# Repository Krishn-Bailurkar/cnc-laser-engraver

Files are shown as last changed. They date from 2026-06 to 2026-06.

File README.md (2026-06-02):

# 🛠️ CNC Laser Engraver Machine

Welcome to the official repository for the **CNC Laser Engraver Machine** project. This is a comprehensive Mechatronics Capstone Project designed to create an adaptable, high-precision, and cost-effective CNC laser engraving platform. 

This repository contains the complete **3D-printable STL model files** for all mechanical components, as well as the project documentation.

---

## 📋 Table of Contents
1. [Project Overview](#-project-overview)
2. [Technical Specifications](#%EF%B8%8F-technical-specifications)
3. [Repository Structure (3D Models)](#%EF%B8%8F-repository-structure-3d-models)
4. [Hardware & Bill of Materials (BOM)](#-hardware--bill-of-materials-bom)
5. [Assembly & Fabrication Guide](#-assembly--fabrication-guide)
6. [Software & Control Configuration](#-software--control-configuration)
7. [Testing & Validation](#-testing--validation)

---

## 🌟 Project Overview

Our goal was to design and develop a CNC (Computer Numerical Control) laser engraver machine capable of engraving various materials such as **wood, acrylic, leather, and metal**. 

The design is built on three core pillars:
*   **Accuracy:** Intricate and high-speed motion control.
*   **Repeatability:** Consistent engraving results across multiple production runs.
*   **Efficiency & Adaptability:** No proprietary hardware/software; customizable to any size or shape.

---

## ⚙️ Technical Specifications

### 📏 Workspace & Dimensions
*   **Engraving Area (Workspace):** $700\text{ mm} \times 700\text{ mm} \times 50\text{ mm}$ ($X, Y, Z$ axes)
*   **Table Size:** $970\text{ mm} \times 979\text{ mm}$ (Outer edges of feet)
*   **Total Machine Footprint:** $1072\text{ mm} \times 1081\text{ mm} \times 540\text{ mm}$ (Clearance of $680\text{ mm}$ to remove Z-axis)

### ⚡ Electrical & Control System
*   **Laser Module:** 5.5W Diode Laser (Wavelength: $450\text{ nm}$, Input Voltage: 12V DC/AC, Active cooling)
*   **Control Board:** Arduino UNO (ATmega328P microcontroller)
*   **Shield:** Arduino CNC Shield V3
*   **Motor Drivers:** A4988 Stepper Motor Drivers (supports full to $1/16$ microstepping, continuous $1\text{A}$ per phase)
*   **Stepper Motors:** NEMA 17 Stepper Motors (12V DC, $1.2\text{A}$ current, $1.8^\circ$ step angle, $22.2\text{ Oz-in}$ unipolar holding torque)
*   **Power Supply:** Switched-Mode Power Supply (SMPS) 12V $5\text{A}$ ($60\text{W}$ rated power)
*   **Motion Transfer:** GT2 Timing Belts (10mm width, 2mm pitch) driven by 20-tooth aluminum pulleys

---

## 🛠️ Repository Structure (3D Models)

All 3D-printable parts are located in the [`STL/`](file:///d:/Krishn's folder/GitHub/CNC laser engerver/STL) directory. They should be printed with at least **45%+ infill** for strength (Core should be printed at **70% infill**).

| Qty | Part Name | STL File Path | Infill | Key Function |
| :--- | :--- | :--- | :---: | :--- |
| 1 | **Core** | [`STL/Core F .STL`](file:///d:/Krishn's folder/GitHub/CNC laser engerver/STL/Core%20F%20.STL) | 70% | The central carriage holding the Z-axis and laser head assembly. |
| 2 | **Corner Bottom** | [`STL/Corner Bottom F 1.stl`](file:///d:/Krishn's folder/GitHub/CNC laser engerver/STL/Corner%20Bottom%20F%201.stl) / [`F 2.STL`](file:///d:/Krishn's folder/GitHub/CNC laser engerver/STL/Corner%20Bottom%20F%202.STL) | 45% | Main corner mounts anchored to the workbench table. |
| 2 | **Corner Top** | [`STL/Corner Top F1.stl`](file:///d:/Krishn's folder/GitHub/CNC/laser/engerver/STL/Corner%20Top%20F1.stl) / [`F 2.STL`](file:///d:/Krishn's folder/GitHub/CNC/laser/engerver/STL/Corner%20Top%20F%202.STL) | 45% | Secure top caps holding the outer axis rails together. |
| 4 | **Feet** | [`STL/Feet F.STL`](file:///d:/Krishn's folder/GitHub/CNC laser engerver/STL/Feet%20F.STL) | 45% | Bottom mounting brackets that secure legs to the table. |
| 4 | **Corner Leg Lock** | [`STL/Corner Leg Lock F.STL`](file:///d:/Krishn's folder/GitHub/CNC laser engerver/STL/Corner%20Leg%20Lock%20F.STL) | 45% | Clamps that secure the vertical legs into the corner bases. |
| 2 | **Truck** | [`STL/Truck F .STL`](file:///d:/Krishn's folder/GitHub/CNC laser engerver/STL/Truck%20F%20.STL) / [`Truck F.stl`](file:///d:/Krishn's folder/GitHub/CNC laser engerver/STL/Truck%20F.stl) | 45% | Carriage blocks moving along the X and Y axes. |
| 4 | **Truck Clamp** | [`STL/Truck Clamp F .STL`](file:///d:/Krishn's folder/GitHub/CNC laser engerver/STL/Truck%20Clamp%20F%20.STL) | 45% | Secure clamping locks for the rail-bearing trucks. |
| 2 | **Lower Belt Mount** | [`STL/Lower Belt F1.stl`](file:///d:/Krishn's folder/GitHub/CNC laser engerver/STL/Lower%20Belt%20F1.stl) / [`F 2.STL`](file:///d:/Krishn's folder/GitHub/CNC laser engerver/STL/Lower%20Belt%20F%202.STL) | 45% | Bottom belt retention and routing guides. |
| 2 | **Upper Belt Mount** | [`STL/Upper Belt F 1.stl`](file:///d:/Krishn's folder/GitHub/CNC laser engerver/STL/Upper%20Belt%20F%201.stl) / [`F 2.STL`](file:///d:/Krishn's folder/GitHub/CNC/laser/engerver/STL/Upper%20Belt%20F%202.STL) | 45% | Top belt retention and tensioners. |
| 2 | **Core Z Clamp** | [`STL/Core Z Clamp 1 F .STL`](file:///d:/Krishn's folder/GitHub/CNC laser engerver/STL/Core%20Z%20Clamp%201%20F%20.STL) / [`2 F .STL`](file:///d:/Krishn's folder/GitHub/CNC laser engerver/STL/Core%20Z%20Clamp%202%20F%20.STL) | 45% | Holds the vertical Z rails in place on the central core. |
| 3 | **Core Clamp** | [`STL/Core Clamp F .STL`](file:///d:/Krishn's folder/GitHub/CNC laser engerver/STL/Core%20Clamp%20F%20.STL) | 45% | Main clamping block surrounding the core gantry rails. |
| 1 | **Core Clamp Y** | [`STL/Core Clamp Y F .STL`](file:///d:/Krishn's folder/GitHub/CNC laser engerver/STL/Core%20Clamp%20Y%20F%20.STL) | 45% | Y-axis alignment clamp for the core carriage. |
| 1 | **Lower Tool Plate** | [`STL/Lower Tool Plate F.STL`](file:///d:/Krishn's folder/GitHub/CNC laser engerver/STL/Lower%20Tool%20Plate%20F.STL) | 45% | Mount plate for low-profile Z-axis tools/accessories. |
| 1 | **Upper Tool Plate** | [`STL/Upper Tool Plate F .STL`](file:///d:/Krishn's folder/GitHub/CNC laser engerver/STL/Upper%20Tool%20Plate%20F%20.STL) | 45% | Main structural attachment plate for the laser module. |
| 1 | **Z Motor Mount** | [`STL/Z Motor F .STL`](file:///d:/Krishn's folder/GitHub/CNC laser engerver/STL/Z%20Motor%20F%20.STL) | 45% | Mounting plate for the Z-axis stepper motor. |
| 1 | **Z Coupler** | [`STL/Z Coupler F .STL`](file:///d:/Krishn's folder/GitHub/CNC laser engerver/STL/Z%20Coupler%20F%20.STL) | 45% | Rigid coupling to connect Z-motor to the leadscrew. |
| 1 | **Nut Trap** | [`STL/Nut Trap .STL`](file:///d:/Krishn's folder/GitHub/CNC laser engerver/STL/Nut%20Trap%20.STL) | 45% | Traps the leadscrew copper nut for vertical travel. |
| 4 | **Stop Block** | [`STL/Stop Block 25.STL`](file:///d:/Krishn's folder/GitHub/CNC laser engerver/STL/Stop%20Block%2025.STL) | 45% | Limit blocks to prevent over-travel on the axes. |
| 2 | **Wire Darryl** | [`STL/Wire Darryl.STL`](file:///d:/Krishn's folder/GitHub/CNC laser engerver/STL/Wire%20Darryl.STL) | 45% | Spacer block used to perfectly gauge pulley height during assembly. |

---

## 🛒 Hardware & Bill of Materials (BOM)

| Item Description | Quantity | Purpose |
| :--- | :---: | :--- |
| **Nema 17 Stepper Motors (50 OZ-in+)** | 4 (or 5) | Powering the Dual X and Dual Y axes (and optional Z-axis). |
| **GT2 Belt (10mm width)** | 4 | Drive belts for X and Y axes. |
| **GT2 Pulley (20T, 10mm width, 5mm bore)**| 4 | Fitted onto motor shafts to drive belts. |
| **Idler Pulley (20T, 10mm width, 5mm bore)**| 8 | Passive pulleys for belt loops. |
| **608RS Ball Bearings** | 45 | Used in Trucks and Core carriages for smooth rolling on rails. |
| **Arduino UNO + CNC Shield V3** | 1 | Microcontroller brain and expansion board. |
| **A4988 Stepper Drivers** | 4 | Control current supply to steppers. |
| **12V 5A Switched Power Supply (SMPS)** | 1 | Powers control board and stepper motors. |
| **5.5W Diode Laser Module** | 1 | Light/heat source for engraving. |
| **M8x40mm (or 5/16" x 1.5") Bolts & Locknuts**| 44 | Primary truck and carriage structural fasteners. |
| **M5x30mm Screws & Locknuts** | 60 | Base feet, leg locks, and corner clamps. |
| **M3x10mm Screws** | 22 | Motor mounting and minor fixtures. |
| **M2.5x12mm Screws** | 8 | Optional limit switch mounting. |
| **T8 Leadscrew + Copper Nut** | 1 | Z-axis vertical drive. |
| **5mm to 8mm Flexible Coupler** | 1 | Z-motor shaft to leadscrew coupler. |
| **Stainless Steel Rails (25mm OD)** | 4 (outer) + 2 (gantry)| Core linear guide rails. |

---

## 🔨 Assembly & Fabrication Guide

For an in-depth visual step-by-step walkthrough, please refer to the complete capstone document: [report from chapter.pdf](file:///d:/Krishn's folder/GitHub/CNC%20laser%20engerver/report%20from%20chapter.pdf).

### 1. Base Setup (Legs & Corners)
1. Mount the four **Feet** [`STL/Feet F.STL`](file:///d:/Krishn's folder/GitHub/CNC laser engerver/STL/Feet%20F.STL) securely onto a flat workbench using wood screws.
2. Insert vertical steel pipe legs into the feet and lock them in using the **Corner Leg Locks** [`STL/Corner Leg Lock F.STL`](file:///d:/Krishn's folder/GitHub/CNC laser engerver/STL/Corner%20Leg%20Lock%20F.STL) and M5x30mm hardware.
3. Fit the **Corner Bottoms** [`STL/Corner Bottom F 1.stl`](file:///d:/Krishn's folder/GitHub/CNC laser engerver/STL/Corner%20Bottom%20F%201.stl) onto the leg tops.
4. Align, measure, and cross-check the diagonals diagonally (ensure $<1\text{ mm}$ deviation) to secure a perfectly square frame.

### 2. Carriage Trucks & Squaring
1. Assemble the **Trucks** [`STL/Truck F .STL`](file:///d:/Krishn's folder/GitHub/CNC laser engerver/STL/Truck%20F%20.STL) by press-fitting the 608RS bearings using M8x40mm bolts. 
2. Adjust the tension bolts evenly so that the carriage moves smoothly under a 45-degree tilt test.
3. Mount the **Truck Clamps** [`STL/Truck Clamp F .STL`](file:///d:/Krishn's folder/GitHub/CNC laser engerver/STL/Truck%20Clamp%20F%20.STL) loosely.

### 3. Pulleys & Motors
1. Mount the **NEMA 17** motors onto the trucks using M3x10mm screws.
2. Slip the **GT2 Pulleys** onto the motor shafts. Use the **Wire Darryl** [`STL/Wire Darryl.STL`](file:///d:/Krishn's folder/GitHub/CNC laser engerver/STL/Wire%20Darryl.STL) spacer to align the pulley heights relative to the idlers perfectly.
3. Tighten the grab screws onto the flat side of the motor shafts first, using threadlocker (Loctite) if necessary.

### 4. Gantry & Core Assembly
1. Place the central **Core** [`STL/Core F .STL`](file:///d:/Krishn's folder/GitHub/CNC laser engerver/STL/Core%20F%20.STL) onto the center rails.
2. Align the crossing X and Y axis gantry rails. 
3. Square the trucks relative to each corner base, adjusting truck tension bolts by $1/16\text{th}$ increments to get perfect symmetry.

---

## 🔌 Software & Control Configuration

### Firmware
The Arduino UNO is flashed with **GRBL v1.1** firmware, an open-source, high-performance C-based motion controller optimized for AVR microcontrollers.
*   **Supported Features:** Real-time acceleration/deceleration, standards-compliant G-code processing, soft limits, and active home cycle.

### Host Software
We highly recommend **LaserGRBL** (an open-source Windows UI) to run and control the machine:
1. Connect via USB at **115200 Baud Rate**.
2. Load raster designs (BMP, JPEG, PNG) or vector graphics (SVG, DXF).
3. LaserGRBL translates images into clean G-code, handling laser power scaling ($S$-commands) and rapid feeds ($G0/G1$).

---

## 🧪 Testing & Validation

Our validation protocol successfully tested all key functional blocks:
*   **Accuracy Check:** Cross-diagonal measurement error within $\pm0.5\text{ mm}$.
*   **Laser Control:** Verified TTL/PWM power scaling from $0\%$ to $100\%$ intensity on wood and acrylic.
*   **Safety Integration:** Configured emergency stop buttons and active limit switch homing.
*   **Cooling Efficiency:** Forced-air fan cooling keeps the 5.5W laser module at a stable operating temperature below $40^\circ\text{C}$ during intensive 2-hour continuous runs.

---

*Mechatronics Engineering Capstone Project. Built for durability, precision, and open-source accessibility.*

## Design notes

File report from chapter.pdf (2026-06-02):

CNC Laser Engraver Machine

Department Of Mechatronics | 1

## CHAPTER 1

## 1.1 INTRODUCTION

The CNC laser engraver machine is a platform to precisely control motion.

This can easily be a laser engraver or a laser engraver CNC machine.

CNC stands for Computer Numerical Control and has been around since the

early 1970's. Prior to this, it was called NC, for Numerical Control. (In the early

1970's computers were introduced to these controls, hence the name change.) While

people in most walks of life have never heard of this term, CNC has touched almost

every form of manufacturing process in one way or another. If you'll be working in

manufacturing, it’s likely that you'll be dealing with CNC on a regular basis.

In a typical NC system, the motion and machining instructions and the

related numerical data, together called a part program, used to be written on a

punched tape. The part program is arranged in the form of blocks of information,

each related to a particular operation in a sequence of operations needed for

producing a mechanical component. The punched tape used to be read one block at

a time. Each block contained, in a particular syntax, information needed for

processing a particular machining instruction such as, the segment length, its cutting

speed, feed, etc. These pieces of information were related to the final dimensions

of the work piece (length, width, and radii of circles) and the contour forms (linear,

circular, or other) as per the drawing. Based on these dimensions, motion

commands were given separately for each axis of motion. Other instructions and

related machining parameters, such as cutting speed, feed rate, as well as auxiliary

functions related to part clamping, are also provided in part programs depending on

manufacturing specifications such as tolerance and surface finish. Punched tapes

are mostly obsolete now, being replaced by magnetic disks and optical disks

Computer Numerically Controlled (CNC) machine tools, the modern versions of

NC machines have an embedded system involving several microprocessors and

related electronics as the Machine Control Unit (MCU). Initially, these were

developed in the seventies in the US and Japan. However, they became much more

popular in Japan than in the US. In CNC systems multiple microprocessors and programmable logic controllers work in parallel for simultaneous servo position

and velocity control of several axes of a machine for contour cutting as well as

monitoring of the cutting process and the machine tool. Thus, milling and boring

machines can be fused into versatile machining centres. Similarly, turning centres

can realize a fusion of various types of lathes. Over a period of time, several

additional features were introduced, leading to increased machine utilization and

reduced operator intervention.

## 1.2 SCOPE OF THE CAPSTONE PROJECT

Problem Statement: Our goal is to design and develop a CNC (Computer

Numerical Control) laser engraver machine that can efficiently and accurately

engrave various materials, such as wood, acrylic, metal, and leather. The machine

should be capable of precise positioning and high-speed movement to achieve

detailed and intricate designs.

Objectives: Design and develop a CNC Laser Engraver Project aims to provide a

cutting-edge, reliable, and user-friendly solution for businesses, hobbyists, and

artists, enabling them to achieve precise and efficient engraving on various

materials.

Capstone Project Description: 1. Accuracy.

2. Repeatability.
3. Efficiency.

Capstone Project Deliverables:

1. Machine Working: The machine that can provides stability, precision, and

durability for the machine's operation.

2. User manual: A guide for users to understand how to load, configure and

use the machine.

3. Source code: The complete source code for the machine.
4. Test results: Results of the tests performed to check the accuracy and

performance of the machine.

Key Milestones:

1. Project Conception and Initiation
2. Planning and Requirements
3. Project Design
4. Project Development
5. Testing

Constraints:

- Technical constraints: This could include the hardware and software

requirements for the system, such as the controller, power supply, and lathe

machine. The system should also be designed to work under different

environmental conditions such as high humidity, and extreme temperatures.

- Time constraints: The project should be completed within a specific

timeframe, with milestones set along the way to ensure that progress is being

made.

Estimated Capstone project Duration: 12 weeks.

Estimated Capstone project cost: Rs. 30,540/-

## CHAPTER 2

## 2.1 CAPSTONE PROJECT PLANNING

### 2.1.1 WORK BREAKDOWN STRUCTURE-DELIVERABLES

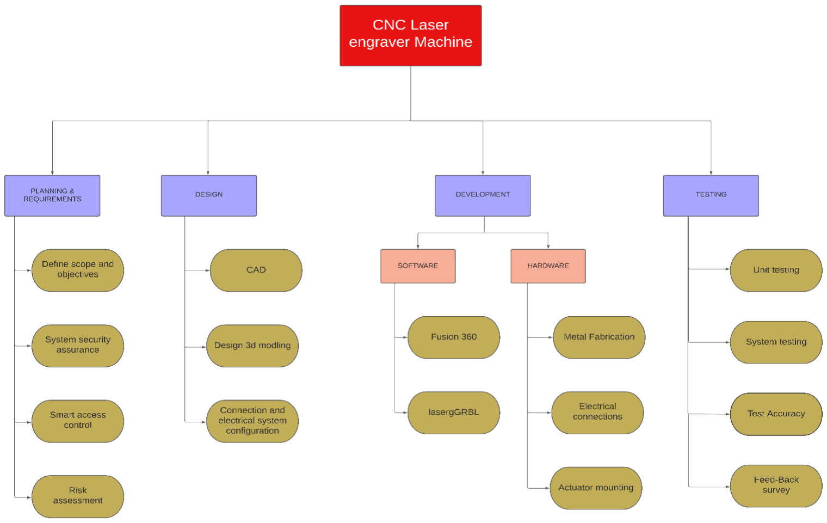
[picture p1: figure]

Figure no: 1

### 2.1.2 TIMELINE DEVELOPMENT – SCHEDULE

Table no: 1

Task | Task Name | Start | Finish | Duration
Phase 1 | PRE-REQUIREMENTS TO START | 27/2/2023 | 03/3/2023 | 04 Days
Task 1 | Research | 27/2/2023 | 01/3/2023 | 03 Days
Task 2 | Project Initiation | 01/3/2023 | 03/3/2023 | 03 Days
Phase 2 | PLANNING & REQUIREMENTS | 04/3/2023 | 17/3/2023 | 12 Days
Task 1 | Define scope and objectives | 04/3/2023 | 11/3/2023 | 07 Days
Task 2 | Smart access control and risk assessment | 13/3/2023 | 17/3/2023 | 05 Days
Phase 3 | DESIGN | 18/3/2023 | 29/3/2023 | 10 Days

Task 1

CAD Design, Design 3d modelling and design the electrical system configuration

| | 18/3/2023 | 29/3/2023 | 10 Days
Phase 4 | DEVELOPMENT | 30/3/2023 | 16/5/2023 | 40 Days
Task 1 | Software Installation | 30/3/2023 | 1/4/2023 | 25 Days
Sub task 1 | Fusion 360 | 30/3/2023 | 11/4/2023 | 10 Days
Sub task 2 | LaserGRBL | 12/4/2023 | 29/4/2023 | 15 Days
Task 2 | Metal Fabrication , Electrical
| connections and Actuator mounting | 29/4/2023 | 16/5/2023 | 15 Days
Phase 5 | TESTING | 16/5/2023 | 30/5/2023 | 14 Days
Task 1 | Unit testing and system testing | 16/5/2023 | 23/5/2023 | 07 days
Task 2 | Test documentation and feed-back
| survey | 24/5/2023 | 01/6/2023 | 07 Days

### 2.1.3 COST BREAKDOWN STRUCTURE (CBS)

Table no: 2

SL No. | PARTICURALS | Qty. | COST IN RUPEES
1. | Nema 17 | 4 | 2,700/-
2. | Belt GT2 10mm | 4 | 799/-
3. | Pulley 10mm GT2 | 4 | 499/-
4. | Idler pulley 10mm | 8 | 2,392/-
5. | Power Supply | 1 | 570/-
6. | Wire kit | 1 | 400/-
7. | Bearings | 45 | 1,245/-
8. | Arduino UNO | 1 | 1,172/-
9. | CNC shield | 2 | 240/-
10. | Motor driver | 4 | 599/-
11. | Mounting hardware | - | 500/-
12. | Filament | 2kg | 1,598/-
13. | 5.5W Laser | 1 | 17,826/-
TOTAL | | | 30,540/-

### 2.1.4 CAPSTONE PROJECT RISKS ASSESSMENT

- Technical Risks:
- Malfunctioning of sensors.
- Mechanical Failure.
- Software Malfunction.
- Electrical or Electronic Failure.
- Calibration Issues.
- Schedule Risks:
- Equipment delivery delays.
- Resource availability.
- Design changes.
- Testing and calibration.
- Unforeseen events.
- Security Risks:
- Physical security.
- Operator safety.
- Intellectual property theft.
- Compliance.
- Legal Risks:
- Patent infringement.
- Product liability.
- Employment law.
- Environmental regulations.
- Contract disputes.

## 2.2 REQUIREMENTS SPECIFICATION

### 2.2.1 FUNCTIONAL

- Nema 17 Stepper Motor: Nema 23 stepper motors, a stepper motor,

also known as step motor or stepping motor, is a brushless DC

electric motor that divides a full rotation into a number of equal

steps.

Figure No: 1 | Figure No: 2
- GT2 Belt 10mm: 10mm GT2 Timing Belt is designed to convert
rotational power | from various motors such as | stepper

motors (http://www.diyelectronics.co.za/store/97-stepper-motors) and servo motors (http://www.diyelectronics.co.za/store/62-servos) into linear motion.

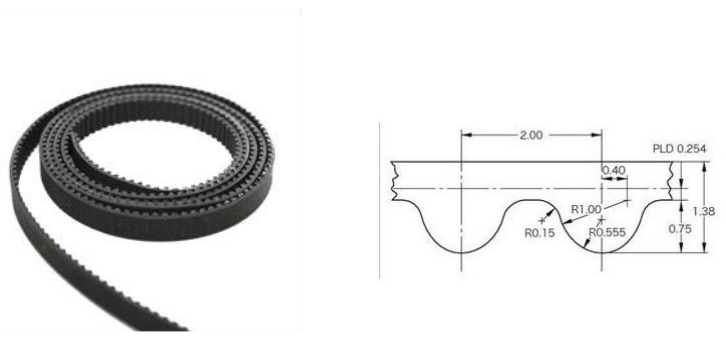
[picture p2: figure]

Figure No: 3 | Figure No: 4
- Pulley GT2

Aluminium 20T GT2 timing pulley has a high-quality shiny surface

appearance and robust construction, longer working life. The

rounded teeth of this tooth and belt are engaged together longer

providing a smoother transition between teeth, good performance

for Laser engraver.

Figure No: 5

- POWER SUPPLY

A switched-mode power supply, sometimes known as a switch-

mode power supply or 'SMPS', is an electronic power supply that

integrates a switching regulator for efficient electrical power

conversion. Like other supplies, an SMPS transfers power from a

DC or AC source to DC loads while converting voltage and current.

Figure No: 6

- CONTROL BOARD:

In controller we have used a Microcontroller called Arduion UNO

board and two CNC shields and some stepper motor driver.

- Arduion UNO:

The Arduino Uno is an open-source (https://en.wikipedia.org/wiki/Open-source) microcontroller board (https://en.wikipedia.org/wiki/Single-board_microcontroller) based on

the Microchip (https://en.wikipedia.org/wiki/Microchip_Technology) ATmega328P (https://en.wikipedia.org/wiki/ATmega328P) microcontroller (https://en.wikipedia.org/wiki/Microcontroller) (MCU) and developed

by Arduino.cc (https://en.wikipedia.org/wiki/Arduino) and initially released in 2010.

Figure No: 7

- CNC SHIELD

The Arduino CNC Shield makes it easy to get your CNC projects up

and running in a few hours.

Figure No: 8

- A4988 Stepper Motor Driver

A4988 Stepper Motor Driver is a carrier board or breakout board for

Allegro’s A4988 DMOS Microstepping Driver with current limiting and

overcurrent protection.

Figure No: 9

- LASER MODULE

It has a variable lenses to set the focus. The aluminium housing and forced

air cooling ensures efficient cooling for optimal operation and long service

life. The intensity of the laser can be adjusted via the TTL/PWM

signal. Please see the table below for the materials that can be processed

with this laser.

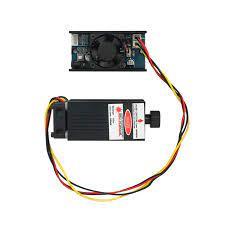
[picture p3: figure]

Figure No: 10

### 2.2.2 USER INPUT

The user input in a CNC laser engraving machine varies according

on the machine and its interface. However, here are some examples of

frequent sorts of user inputs:

- Design File: The user can supply a digital design file in a format that the

CNC laser engraver machine can read. This might be a vector file (SVG,

DXF) or a raster image file (BMP, JPEG) with the artwork or text to be

engraved.

- Settings: The user can choose numerous engraving process settings. This

may include laser power, engraving speed, engraving depth or intensity,

scanning pattern, and other machine-specific variables.

- Material Selection: The user may be required to pick the type of material

on which to engrave. Varied materials have varied qualities, therefore the

machine may need different settings for each material to provide the best

results.

- Positioning and Alignment: To properly position the laser head on the

work piece, the operator may need to enter coordinates or utilise manual

controls. This guarantees that the engraving is correctly and precisely set.

- Start and Stop Commands: After defining the design file, parameters,

material, and placement, the user may begin the engraving process by

issuing a start command. They can also use a stop command to pause or

terminate the engraving operation.

It's worth noting that the user interface and input techniques varies amongst

CNC laser engraving machines. Some machines may feature physical buttons,

knobs, and touchscreens, whilst others may have software interfaces that allow

users to enter data using a computer or a linked device.

### 2.2.3 TECHNICAL CONSTRAINTS

The technical constrains involved in the project CNC Laser engraver

machine are:

- Laser Power: The engraving speed and depth are determined by the laser

power. The laser's power output must be carefully selected to guarantee that

it is sufficient for the required engraving results. Inadequate power may

result in sluggish or shallow engraving, whilst high power may cause

material damage or excessive heat.

- Laser Type: Different types of lasers, such as CO2 lasers and fibre lasers,

are utilised in laser engravers. Each variety has unique properties such as

power consumption, beam quality, wavelength, and maintenance

requirements. The laser type used is determined by the materials to be

engraved and the desired engraving quality.

- Material Compatibility: Laser engraving works well on particular

materials such as wood, acrylic, glass, and certain metals. However, not all

materials can be etched efficiently using a laser. The equipment must be

constructed to accommodate the unique engraving materials, and the laser

settings must be optimised accordingly.

- Workspace Dimensions: The maximum dimensions of the objects that

may be engraved are determined by the size of the machine's working area.

The machine's design must take into account the needed workspace size,

including the X, Y, and Z axes, to handle varying work piece sizes.

- Precision and Accuracy: To generate intricate and crisp engravings, laser

engraving demands great precision and accuracy. To achieve correct

placement and movement, the machine's mechanical components, such as

the linear guides, stepper motors, and control system, must be properly

chosen and calibrated.

- Cooling and ventilation: Because laser engraving creates heat, suitable

cooling and ventilation systems are required to prevent overheating. To

ensure stable operation and preserve sensitive components, effective cooling systems, such as water or air cooling, must be integrated into the

machine design.

- Control System and Software: The CNC control system and engraving

software are critical to the machine's performance. The laser strength, speed,

and movement should all be precisely controlled by the control system. The

programme should have simple user interfaces, handle several file formats,

and provide complex functionality like as vector engraving and picture

processing.

- Safety Features: Laser engravers produce intense laser beams that can be

dangerous to human users. To prevent operators from unintentional laser

exposure, the machine design must contain suitable safety features such as

enclosure interlocks, emergency stop buttons, and laser safety eyewear.

- Maintenance and serviceability: The machine should be built to be simple

to maintain and service. When troubleshooting, repairs, and component

replacements are required, accessible components, modular designs, and

comprehensive documentation can help.

## 2.3 DESIGN SPECIFICATION

### 2.3.1 SYSTEM DESIGN

### 2.3.1.1 SPECIFICATION:

Not easy to make a specs page when it can have most any specs you

want. The idea behind this is to be extremely adaptable and

inexpensive. Why buy a single use machinewhen you can have one

that does it all for less than the cost of any single function machine.

No proprietary hardware or software, build it any size and shape you

want (more on this later).

### 2.3.1.2 SIZE:

All axis can be any length you prefer, anything over 3 ½′ (1M)

would require small mid-span supports to increase rigidity, of course smaller is better. The kit comes with enough belt for up to

48″ of total outer X and Y axis dimensions (e.g.: 24″x24″, 36″x12″

or any other combination).

The smaller you make this the faster you can move it and the more

rigid/accurateit will be, and more importantly the easier it will be to

get the desired accuracy.

### 2.3.1.3 POWER:

X and Y axis are powered by 2 stepper motors each axis. The

standard would be NEMA 17 in any torque preferably 50 OZ/in and

above. No need for NEMA 23’s or their required larger drivers,

torque is not one of this machines issues.

Belts are used for their accuracy and price. Small belts are used

because each axis has two of them. Ball screws are expensive,

require tuning, and periodic maintenance / adjustments.

### 2.3.1.4 CONTROL:

This is all controlled by any control board you like. The UltiMachine boards

are recommended for the improved design and robust safety features. You

can still use the common Ramps 1.4 or any others boards as well. There are

other Marlin (https://github.com/MarlinFirmware/Marlin) based boards, GRBL, (https://github.com/grbl/grbl) and regular CNC boards as well as.

### 2.3.1.5 SOFTWARE:

There are plenty of free or really inexpensive software options available for

3D printing, CAM, and CAD. I suggest Fusion 360, (http://www.autodesk.com/products/fusion-360/overview) Repetier-host, (http://www.autodesk.com/products/fusion-360/overview)

ESTLCam, (http://www.estlcam.com/) bCNC, etc.

LaserGRBL to run and control CNC Laser engraver machine.

### 2.3.1.6 SIZE CALCULATION:

Figures no: 11 | Figures no: 12

UNITS are in mm

### 2.3.1.7 WORKSPACE

- X-Axis = 700mm
- Y-Axis = 700mm
- Z-Axis = 50 mm

### 2.3.1.8 TABLE SIZE

Table No: 4

### 2.3.1.9 TUBE LENGTHS

Table No: 5

### 2.3.1.10 MATERIAL DIMENSIONS

Table No: 6

### 2.3.1.11 TOTAL MACHINE FOOTPRINT

Table no: 7

### 2.3.2 DESCRIPTION OF COMPONENTS

### 2.3.2.1 PRINTED PART LIST:

Table no: 8

### 2.3.2.2 HARDWARE:

Table no: 9

### 2.3.2.3 COMPONENTS:

Table no 3

- Nema 17 Stepper Motor:
- Rated Voltage | : 12V DC.
- Current | : 1.2A at 4V.
- Step Angle | : 1.8 deg.
- No. of Phases | : 4.
- Motor Length | : 1.54 inches.
- 4-wire, 8 inch lead.
- 200 steps per revolution | : 1.8 degrees.
- Operating Temperature | : -10 to 40 °C.
- Unipolar Holding Torque | : 22.2 Oz-in.
- GT2 Belt 10mm:
- Width – 10mm.
- Tooth Pitch – 2mm.
- Material – Nylon Cover / Fibreglass Reinforced / Neoprene.
- Pulley GT2 :
- Bore Diameter (B) (mm) | -5mm
- Outer Diameter (OD) (mm) | -16mm
- Pitch (GT2) | -2mm
- Belt width | -10mm
- No. of teeth | -16 teeth
- Length (mm) | -16mm
- Weight (gm) | -12gm

- POWER SUPPLY:
- DC Voltage | : 12V
- Rated Current | : 5A
- Current Range | : 0-5A
- Rated Power | : 60W
- Ripple & Noise (maximum) | : 150mV
- Voltage Adjustable Range | : 10-13.2V
- Voltage Tolerance | : ±2.0%
- Line Regulation | : ±0.5%
- Load Regulation | : ±0.5%
- Arduion UNO:
- Microcontroller | : ATmega328P
- Operating Voltage | : 5V
- Input Voltage (recommended) | : 7-12V
- Output Voltage (limit) | : 6-20V
- Digital I/O Pins | : 14
- PWM Digital I/O Pins | : 6
- Analog Input Pins | : 6
- DC Current per I/O Pin | : 20 mA
- DC current for 3.3V Pin | : 50 mA
- Flash Memory | : 32 KB
- SRAM | : 2 KB
- EEPROM | : 1 KB
- Clock Speed | : 16 MHz
- LED_BUILTIN | : 13
- Length | : 68.6 mm
- Width | : 58.4 mm
- Weight | : 25 g
- CNC SHIELD:
- Motor Voltage | : 8 V to 35 V.
- Logic Circuits Voltage | : 3 V to 5.5 V.

- Current | : 2 A (MAX).
- Five step resolutions | : full, 1/2, 1/4, 1/8 and 1/16.
- Protection | : under-voltage, over-current and over-temperature.
- A4988 Stepper Motor Driver:
- Minimum operating voltage | -8 V
- Maximum operating voltage | -35 V
- Continuous current per phase | -1 A
- Maximum current per phase | -2 A
- Minimum logic voltage | -3 V
- Maximum logic voltage | -5.5 V
- Microstep resolutions | -1, 1/2, 1/4, 1/8, 1/16
- Size | -0.6″ × 0.8″
- Weight | -1.3 g
- LASER MODULE
- Wave length | : 450nm.
- Power | : 5500MW.
- Electric current | : <5A.
- Input voltage | : DC AC 12V.
- Working temperature | : -10 ~+40.
- Size | : 33*33*75mm.

## CHAPTER 3

## 3.1APPROACH AND METHODOLOGY

### 3.1.1 TECHNOLOGY USED:

- Laser Technology: CNC laser engravers use laser technology to create

the engraving, which emits a highly focused beam of light that can be

precisely controlled to remove material from the surface and create the

desired marks or patterns. Common types of lasers used in engraving

machines include CO2 lasers, fibre lasers, and diode lasers.

- CNC (Computer Numerical Control): CNC technology is built into

laser engraver equipment. It entails accurately controlling the movement

of the laser head or the work piece using computer software and control

systems. The CNC system analyses digital drawings or instructions and

converts them into synchronised laser motions, allowing for precision

engraving.

- Motion Control: Motion control systems are used by CNC laser

engravers to control the movement of the laser head or the work piece.

Stepper or servo motors are frequently used in conjunction with linear

guides or belts to move the laser or work piece along several axes

(normally X, Y, and occasionally Z). The motion control system

guarantees that the laser is accurately positioned and moved for

precision engraving.

- Cooling Systems: Because laser engraving creates heat, cooling

systems are required to keep the laser components at the appropriate

temperature. These systems frequently use water or air cooling to

minimise overheating and preserve the laser's lifespan and effectiveness.

- Optics and Beam Delivery: Laser engraver machines control and guide

the laser beam using a set of lenses. Mirrors and lenses are commonly

used in these optics to concentrate and direct the laser beam onto the

work piece. Beam delivery systems, such as articulated arms or gantry

systems, allow the laser beam to move around the work piece to engrave

different locations.

- Control Software: CNC laser engraving devices require specialised

control software to function. Users may use this programme to import

or design digital files, select engraving parameters, move the laser or

work piece, and monitor the engraving operation. It also allows you to

customise the laser strength, speed, and other variables to obtain the

desired results.

Based on the problem definition of developing a “CNC LASER

ENGRAVER MACHINE”, the following methodology can be considered:

1. Complex Design: Developing a CNC laser engraver machine

requires expertise in mechanical engineering, electrical engineering,

and computer programming. The design of the machine needs to be

highly precise and complex to ensure its accuracy and reliability.

2. High Development Cost: Developing a CNC laser engraver

machine can be expensive due to the specialized components and

materials required, as well as the advanced technology needed to

control the machine. This can make it challenging to keep the project

within budget.

3. Customization and Flexibility: CNC laser engraver machines are

often customized to meet specific manufacturing requirements,

which can make it difficult to develop a machine that is flexible

enough to meet the needs of multiple customers. This may require

additional development time and cost.

4. Testing and Certification: CNC laser engraver machines are

required to meet various safety standards and regulations, which can

add to the development time and cost. The machine must also be

thoroughly tested to ensure its reliability and accuracy.

5. Competition: The market for CNC laser engraver machines is

highly competitive, and there are many established manufacturers

offering similar machines. This can make it challenging to

differentiate the machine and establish a foothold in the market.

CNC laser engraver machines have a wide range of use cases across various

industries. Some common applications include:

- Personalized and Customized Items: CNC laser engravers

may be used to manufacture personalised and customised goods

such as jewellery, presents, trophies, and awards. They enable

detailed and precise engraving on a variety of materials such as

wood, acrylic, metal, and leather.

- Signage and Branding: CNC laser engravers are extensively

used in the signage sector to make high-quality signs,

nameplates, and logos. They can engrave on materials such as

acrylic, wood, and metal, resulting in professional and long-

lasting signage solutions.

- Industrial Marking and Serializing: CNC laser engravers are

used for industrial marking and serialising, such as engraving

serial numbers, barcodes, QR codes, and identifying tags on

products and components. This aids traceability, inventory

management, and anti-counterfeiting efforts.

- Art and Decorative Objects: Artists and designers use CNC

laser engraving equipment to produce elaborate patterns,

artwork, and ornamental objects on a variety of materials. It

enables accurate details as well as the replication of complicated

patterns.

- Architectural Models and Prototypes: Architectural models

and prototypes are created using CNC laser engravers. They can

engrave precise shapes and textures onto materials such as wood

and foam, making it easier to visualise architectural plans and

speed up the prototype process.

- Woodworking and Furniture Making: CNC laser engravers

are frequently used in the woodworking sector to engrave

elaborate designs, patterns, and trademarks into hardwood

furniture, cabinets, and ornamental objects.

- Electronics and PCB Manufacturing: Electronics and PCB

Manufacturing: CNC laser engravers are used in the electronics

sector to create accurate tracks, labels, and markings on printed

circuit boards (PCBs). They also make it easier to manufacture

specialised electrical components.

3..2 | PROGRAMMING:
| Grbl is a no-compromise, high performance, low cost alternative to
| parallel-port-based motion control for CNC milling. It will run on a
| vanilla Arduino (Duemillanove/Uno) as long as it sports an Atmega
| 328.
| The controller is written in highly optimized C utilizing every clever
| feature of the AVR-chips to achieve precise timing and
| asynchronous operation. It is able to maintain up to 30 kHz of stable,
| jitter free control pulses.
| It accepts standards-compliant g-code and has been tested with the
| output of several CAM tools with no problems. Arcs, circles and
| helical motion are fully supported, as well as, all other primary g-
| code commands. Macro functions, variables, and most canned
| cycles are not supported, but we think GUIs can do a much better
| job at translating them into straight g-code anyhow.

Figures no: 13
3..3 FABRICATION:
- Legs

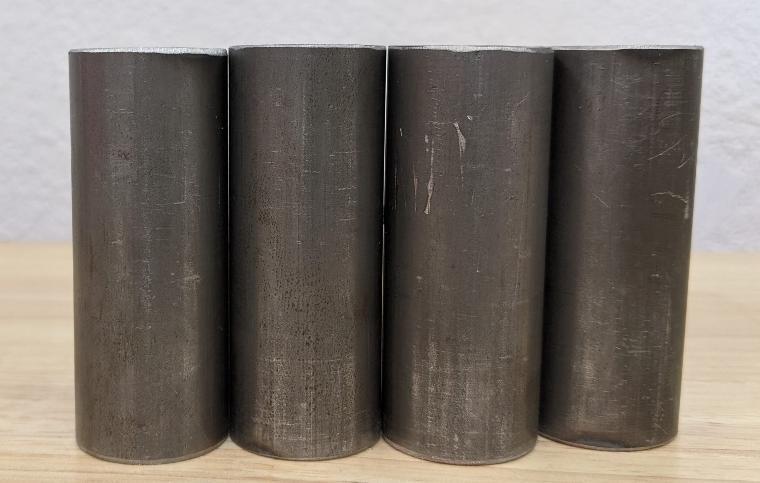
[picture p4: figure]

Figures no: 14

- The leg lengths come from the cut calculator.
- Do whatever it takes to get the legs as equal in length as possible.

This will really helpin levelling and keeping it level.

- In this picture, the one on the far left is too short, so it could either

be shimmed duringassembly or sand/grind the other legs.

- A little extra time here pays off for the life of the machine.

Tip:

Sand, grind, or file the inside and outside edges of all the cuts on the rails and legs. Thisprevents cut wires and eases assembly.

- Tools:

Figures no: 15

- 8mm Socket or nut driver.
- Phillips #2 Screwdriver.
- Legs and Feet

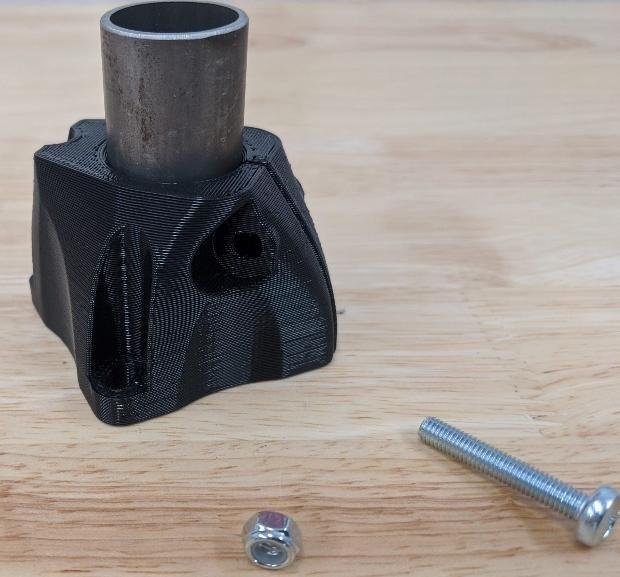
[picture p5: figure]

Figures no: 16

- You will need the legs, printed feet, M5x30 screws and locknuts.

Tip:

It is best to pre-thread all the locknuts before assembly. This will loosen them and preventmangling of the printed parts.

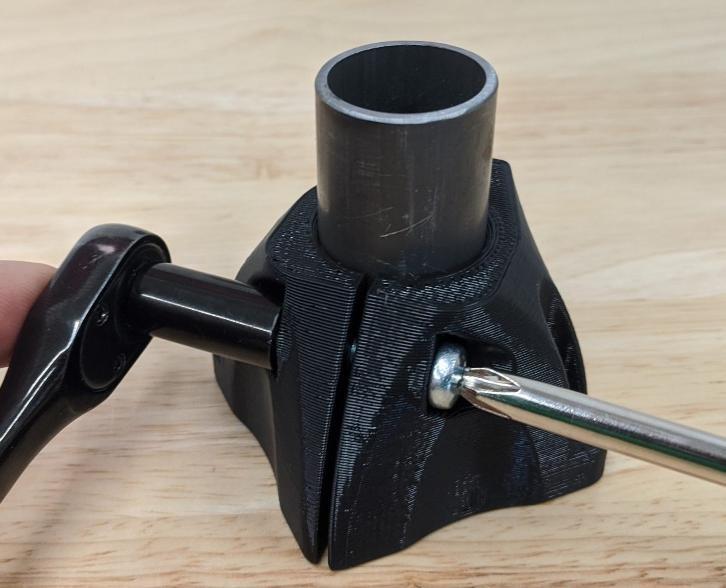
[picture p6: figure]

Figures no: 17

- Insert the leg and make sure it is seated all the way to the table.
- The feet have a small side for the head of the screw and a larger

opening for the nutand socket.

- Snug this screw. Snug means just a ¼ turn past the nut making

contact. This does notneed to be super tight.

- There is a 2+mm gap here, do not try to close the gap.
- BASE LAYOUT:

Figures no: 18

- Use whatever screws are appropriate for your table, these are not

included in the V1 Kits.

- Layout the foot assemblies on your table according to the

dimensions from the cut calculator.

- Notice all the clamping screws are oriented towards the centre of the

build area.

- Screw down the two assemblies along the front edge of the table.

These will be your fixed references.

- Measure as carefully and accurately as you can across the leg tops.

Your machine can only be as accurate as you build it.

- Validate that the front length exactly matches the back length, and

that the left and right lengths match.

- Measure diagonally across the leg tops.

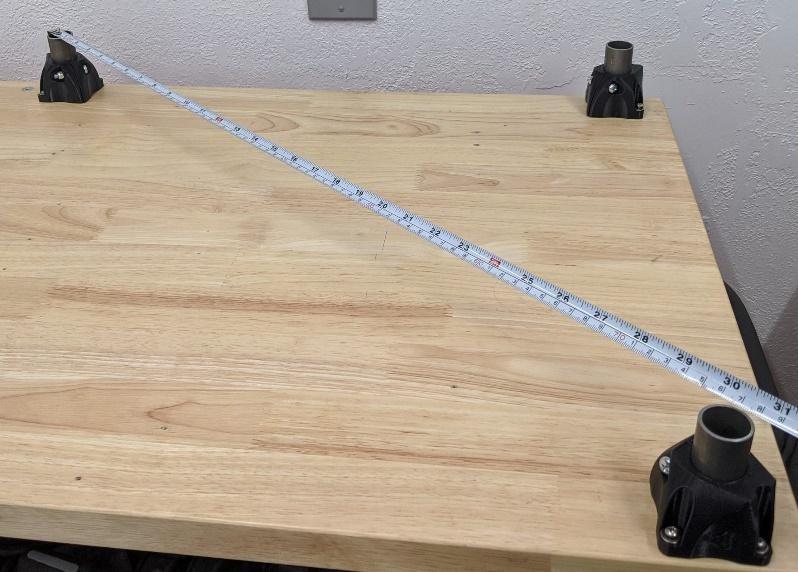
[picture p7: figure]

Figures no: 19

- Compare this measurement to the next one.

Figures no: 20

- This next diagonal should match the previous one.

Squaring this way can be extremely accurate because

any error in the leg locations is multiplied in this

measurement.

- Adjust both rear legs until you are satisfied with the precision.
- Screw in one foot at a time, minor adjustments are possible.
- Triple check the diagonals - they need to be as close as you can get them.

Tip:

Marking and pre-drilling the foot hold downs in the centre of the screw slots makes it much easier to get a square base. It allows a tiny bit of room for adjustment.

- LEG LOCKS:

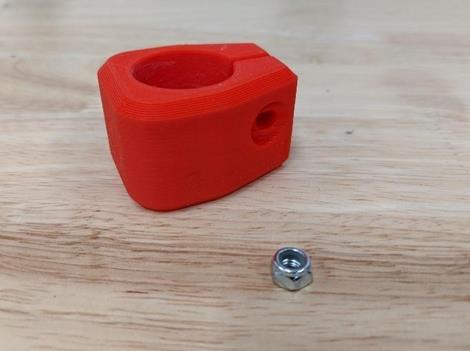
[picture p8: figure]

Figures no: 21

- You will need the printed Corner Leg Locks and M5 locknuts.
- It is best to pre-thread all the locknuts before assembly. This will loosen

them and prevent mangling of the printed parts.

Figures no: 22

- Push the nut into the Corner Leg Lock and fully seat it. If it does not stay on

its own you can use a drop of glue

- If the nut does not stay on its own, you can attach the Corner Bottom very

loosely with its bolt.

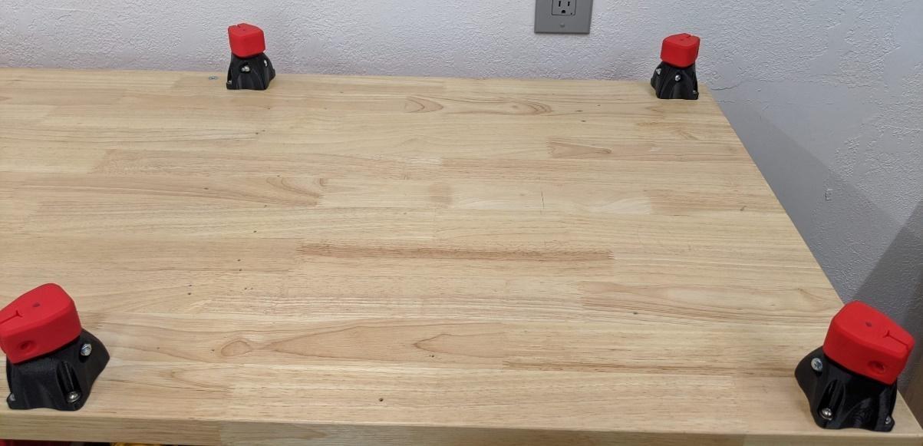
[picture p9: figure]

Figures no: 23

- Fully seat the Corner Leg Locks onto the legs.
- Orient to match the Feet below.
- Do not lock/clamp them.
- CORNER BOTTOMS

Figures no: 24

- You will need the printed Corner Bottoms and Corner Bottom Mirrored and M5x30 screws

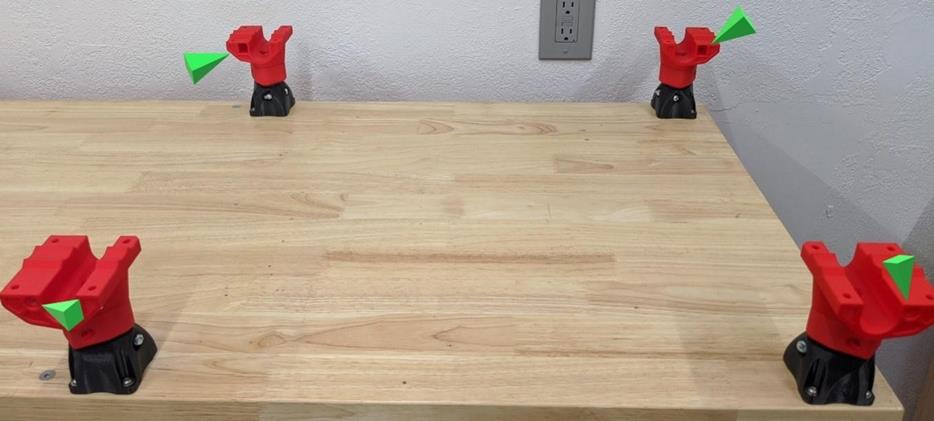
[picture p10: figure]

Figures no: 25

- The Corner Bottoms go on the Leg Locks as shown. Pay attention to

how the belt slider slots are oriented. They point towards each other

on the outside of the build area.

- This picture is taken with the 0, 0 (home) corner in the bottom

nearest left. The corners should be as shown.

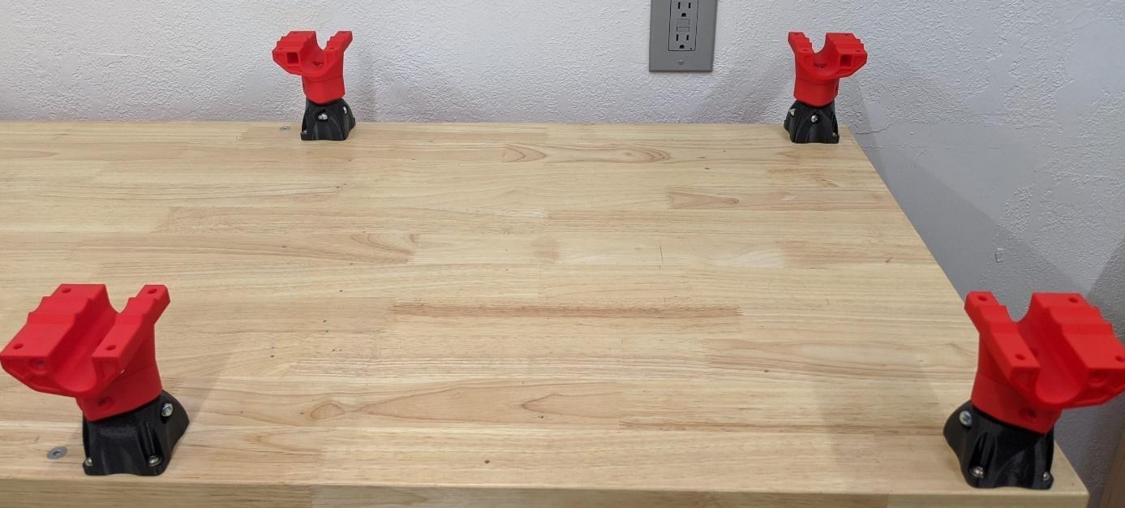
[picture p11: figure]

Figures no: 26

- Get the screws started to hold the Leg Locks and Corner Bottoms

together.

- Leave them loose, just tight enough to make the screw head clear the rail.
- Temporarily adding the Y rails will align the corners.

Figures no: 27

- LOCK THE LEGS

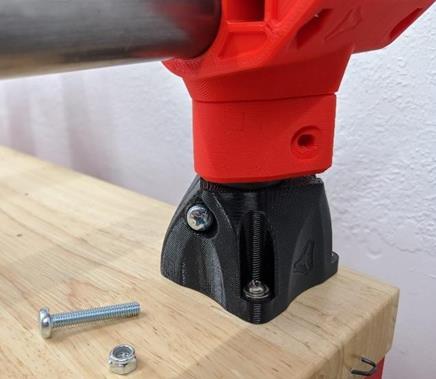
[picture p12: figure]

Figures no: 28

- You will need four sets of the M5 screws and locknuts.
- It is best to pre-thread all the locknuts before assembly. This will loosen

them and prevent mangling of the printed parts.

Figures no: 29

- Snug up all four Leg Locks.
- Snug is just that, ¼ turn past the screw and nut seating into the part. Just

tight enough to make the corner have some resistance if you try to take it

off the leg.

- All clamping parts have a gap. Do not clamp it hard enough to close the gap!
- Now remove the rails and snug up the screw in the bottom of the corner

pieces.

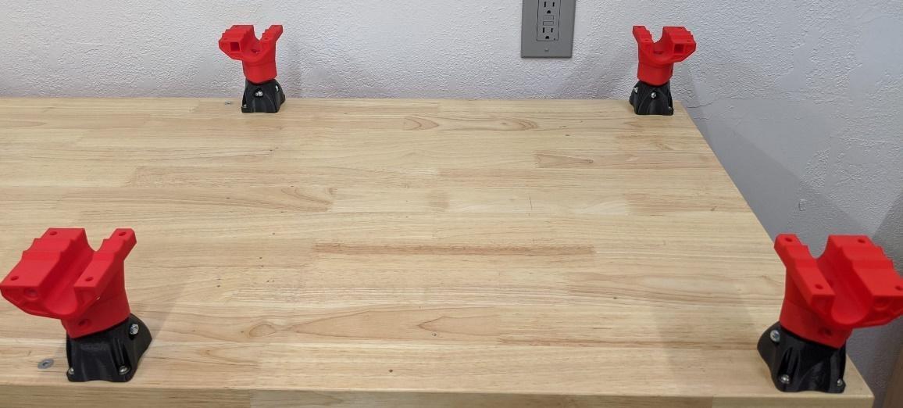
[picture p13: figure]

Figures no: 30

Tip: This screw is tightened after the Leg Locks so the Corner Bottom will correctly and fully seat on the angled joint between the two parts. If you tighten the bottom first, you might have a hard time locking the leg into place or the Corner Bottom could come loose.

- LEVELLING:

Figures no: 31

- Put the Y rails back in place.
- Use whatever means you have at your disposal to assure all four

corners are at the same level.

- If you were careful with your leg lengths this should be level already.
- Loosening the screws and giving the corners a light tap can seat them

a tiny bit farther if needed.

- FINAL CHECK:

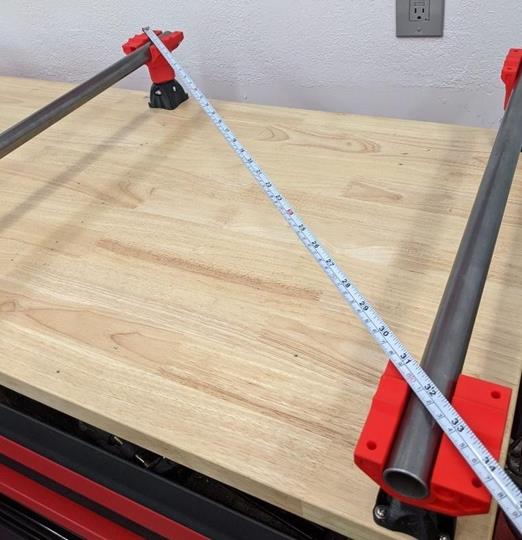
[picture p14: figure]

Figures no: 32

- Best practice is to check your work at every step.
- Measure the diagonal measurement to the best of your abilities.

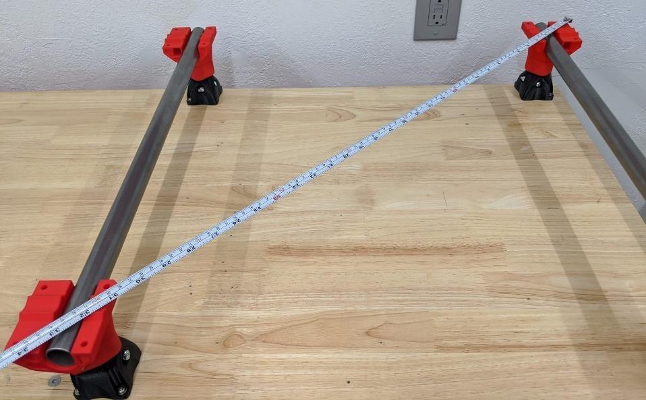
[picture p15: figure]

Figures no: 33

- This diagonal should match. You should aim for no more than 1 mm deviation.
- If there is an issue, loosen the screws into the table and nudge a leg assembly.
- ASSEMBLING THE TRUCKS
- BEARINGS

Figures no: 34

- You will need 5 sets of 5/16 x 1 ½” (M8 x 40mm) bolts and

locknuts.

- Two ½” sockets and ratchets (or 13mm for M8’s).

- 5 bearings.
- Printed Truck and Truck Mirrored parts.
- TENSION BOLTS

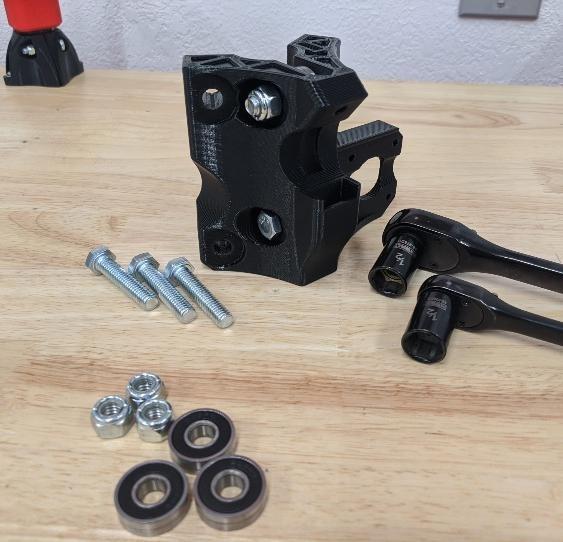
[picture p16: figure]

Figures no: 34

- Insert the bearings in the Truck and fit the bolts.
- Just seat the locknuts, they will get adjusted later. Leave them loose. Note:

Pay attention to the direction of the bolt heads on these two tension bolts.

- STATIONARY BEARINGS
- Fit the last 3 bearings and bolt sets.
- Notice the bolt orientation, nuts towards the rails.
- Snug these up. About 7in/lbs.

Figures no: 35

Caution:

Using ratchets makes over tightening the bolts very easy. There are small 1mm built in spacers in the printed parts, if you crush these you are about 3x too tight. Loose is better thantight. If you work on your own car, it is way less that any bolt you have ever tightened.

- SET THE TRUCK TENSION

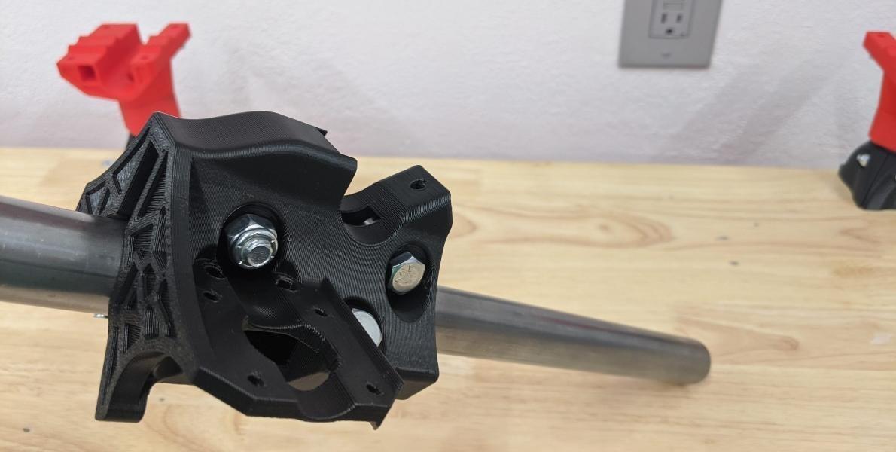
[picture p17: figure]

Figures no: 36

- Insert a rail into the Truck.
- You are looking for all bearings to make contact and just a hint

of tension. If you tip the rail at a 45 degree angle the Trucks

should slowly move. Too tight and theywillstay, too loose and

they will drop right off.

- Tension both bolts evenly - for a new print this should

actually just be good with no extra tension needed. If this is

the case, just snug up the tension bolts until the heads and

nuts are touching the plastic. Holding not adding to the

current tension.

Caution:

If you have to really torque down on these bolts you could have the wrong sized rails or parts.The same thing applies if they are too tight, although you can let them sit overnight with no tension on the bolts to see if they loosen up a bit.

- TRUCK CLAMP

Figures no: 37

- You will need the printed Truck Clamps.
- M5 x 30mm screw and locknut.
- #2 screwdriver.

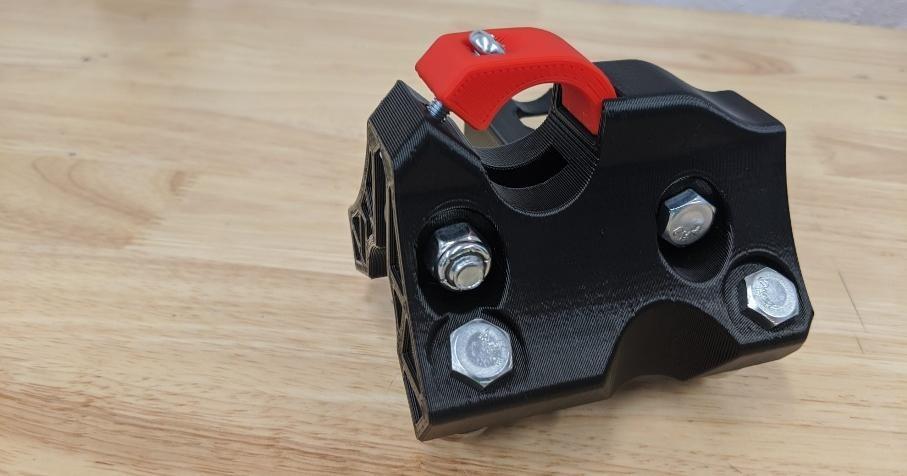
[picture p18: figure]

Figures no: 38

- Leave these loose, just engaging the nut locks. The rail will be added later.

Tip:

For all the screws with captured nuts it is best to pre-thread them to loosen them up a bit toprevent ruining the printed parts.

- Tuck in the idlers into the pocket in the Trucks.
- Tighten the screws just tight enough to seat the nut all the way then back off

a ½ turn.

- Ensure the idlers are free spinning.
- PULLEYS

Figures no: 39
- Steppers
- Pulleys
- Wire Darryl / pulley spacer
- (optional) Loctite

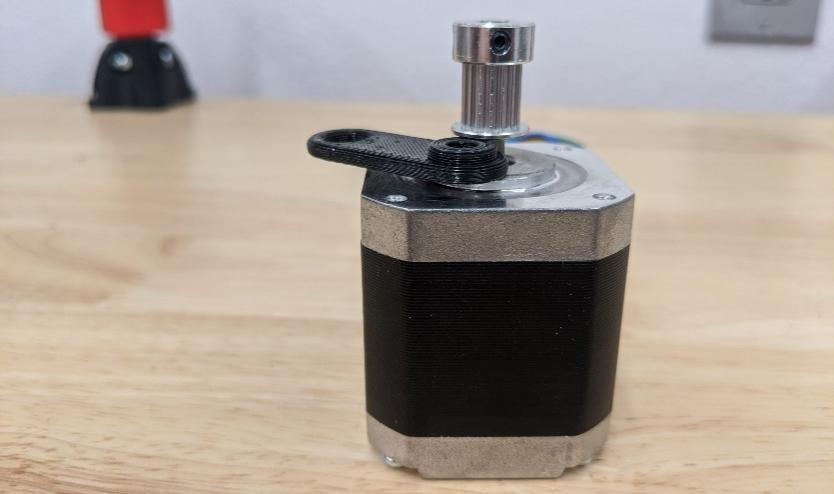
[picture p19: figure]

Figures no: 40

- You can use the Wire Darryl to set the pulley height or just do

it by eye in the nextstep.

Figures no: 41

- Make sure the pulley is aligned with the idlers.
- (optional) Add Loctite to the grub screws, even a bit on the stepper

shaft can help.

- Tighten the grub screw on the stepper shaft flat first.
- Tighten the second grub screw.
Tip:

Loose pulleys are probably the number one issue we see on both the CNC Laser engraver machine builds. They cause all sort of erratic behavior and false “skipped steps”. Take your time and do this correctly. Notice it does not say tighten the heck out of them. Get them on in the right order,directly on the flat, and Loctite is your friend.

- STEPPERS

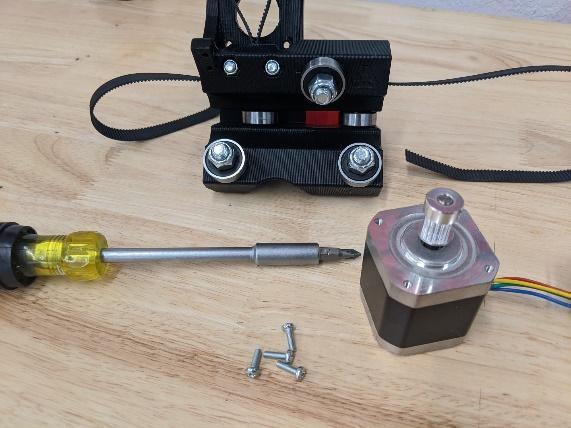
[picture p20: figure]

Figures no: 42
- M3 x 10mm screws.
- #1 screwdriver.
- Truck assemblies and stepper assemblies.

Figures no: 43

- Snug down the screws evenly.
- Double-check the pulley and idlers are still aligned.
- OPTIONAL END STOPS

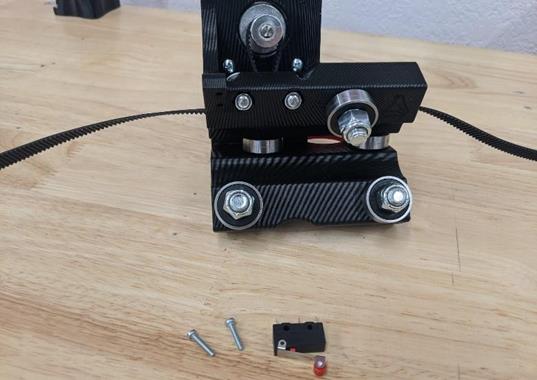
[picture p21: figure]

Figures no: 44

- M2.5 x 12 screws (or #3 x ½” wood screws).
- #1 screwdriver.
- Limit switches.
- Orient the end stop so the trigger is nearest the belt and rail.

Figures no: 45

## - CORNER TOPS AND RAILS:

- TOPS

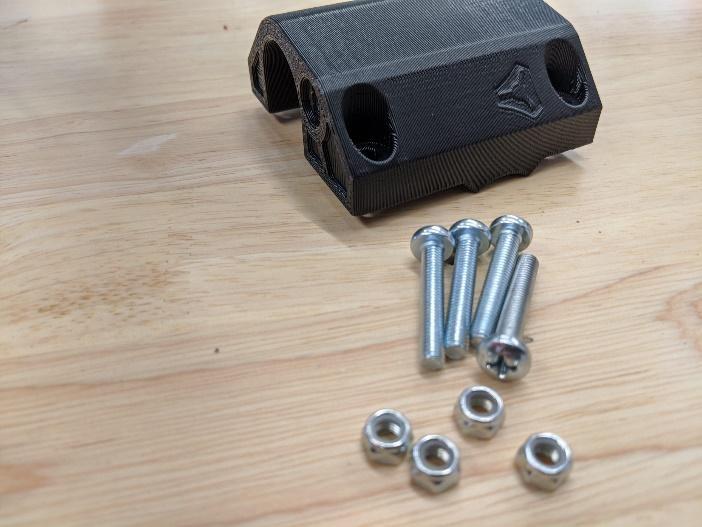
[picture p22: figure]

Figures no: 46

- You will need the printed Corner Top and Corner Top Mirrored parts.
- M5 screws and nuts.
- All 4 X and Y rails.
- Truck assemblies from previous step.
- #2 Screwdriver.

- LAYOUT

Figures no: 47

- Use this picture to orient the Trucks and sort out your X and Y rails
- You do not need the gantry rails at this point, they are just in

this picture to clarifythe position of the Trucks.

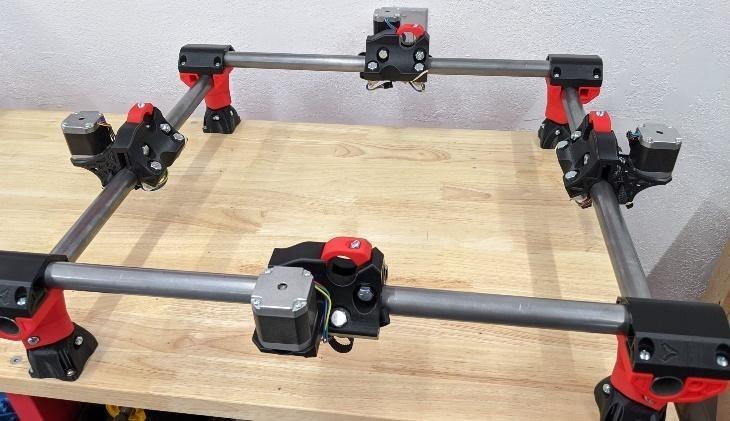
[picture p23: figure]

Figures no: 48

- Add the tops.

- Pay close attention to the belt slides: they should be on the

opposite rails of theCorner Bottom parts.

- Add the screws and nuts and lightly seat them all. Caution;

With all the captured nuts you should pre-thread the screws at least once to loosen thelocknuts up a bit to not destroy the printed parts.

Figures no: 49

- Notice the even gap in the corner pieces. They all should have this.
- Slightly snug down the screws evenly, leaving an even gap on all

sides.

- Snug means the rails will still be able to rotate if you try.

You should feel someresistance though.

- Do not over tighten these screws
- TRUCK SQUARING
- New to the Primo version, before moving on it is best to square your

Trucks.

- Clamp in your gantry rails.
- Move the axis around to settle it.
- Measure from the Trucks on the same axis to either corner (yellow

arrow).

- Now you can move the Trucks by very slightly tightening the tension

bolts.

Figures no: 50

- Start small: try 1/16th of a turn (green arrows).
- Too tight and it will stop moving.
- Loosening will relax it opposite the green arrows.
- Check both axes, again looking for 1mm or under.
- Remove the gantry rails.

## CHAPTER 4

## 4.1 TESTS AND VALIDATION

### 4.1.1 TEST PLAN:

- Introduction
- Objective: This test plan's objective is to explain the testing

strategy for the CNC Laser Engraver Machine project.

- Scope: The test plan will include the CNC Laser Engraver

Machine's functional and non-functional testing operations.

- Objectives
- To confirm that the CNC Laser Engraver Machine fits the

criteria.

- To discover and disclose any flaws or problems.
- To validate the machine's performance, dependability, and

safety.

- To guarantee that the CNC Laser Engraver Machine works well

with various materials and designs.

### 4.1.2 TEST APPROACH

- Unit Testing: Individual components of the CNC Laser

Engraver Machine will be separately tested to ensure their

operation.

- Integration Testing: The integration of various components

will be tested to verify that they perform flawlessly together.

- System Testing: The entire CNC Laser Engraver Machine

will be checked to ensure its general operation.

- Performance Testing: To confirm that the machine satisfies

the specified standards, its performance will be evaluated

under varied workloads.

- Usability Testing: The machine's usability will be evaluated

from the perspective of an end-user to determine its user-

friendliness and simplicity of operation.

- Safety Testing: The machine's safety features will be

evaluated to verify they work as intended and meet safety

regulations.

- Compatibility Testing: The machine will be tested with

various materials and designs to guarantee that it operates

well in a variety of circumstances.

- Regression Testing: Following each modification or update,

regression testing will be performed to ensure that new

changes do not impair current functionality.

### 4.1.3 FEATURES TESTED

- Power Output:

The laser engraver uses a 5.5W laser module to determine

the intensity and depth of the engraving.

- Engraving Area:

The machine has a working area of 700mm/700mm.

- Frame and Construction:

To maintain stability throughout the engraving process, the

machine have a solid and durable frame. To offer stiffness, we have

used stainless steel and 3D printed parts.

- Controller Software:

The machine is compatible with laserGRBL software, which

serves as the engraving process's controller. We use the programme

to input designs, control the laser's movement, change power

settings, and manage other factors.

- Communication:

The laser engraver may feature many communication

options, such as USB which allow you to connect it to a computer.

- Safety measures:

Laser engravers are often equipped with safety measures to

keep users safe. These incorporate laser radiation-containment

enclosures, emergency stop buttons, and safety interlocks to avoid

unintentional exposure to the laser beam.

- Software Features:

LaserGRBL software provide functionality for design

modification, vector tracing, picture manipulation, and laser

parameter control. It also include settings for engraving speed,

power, and resolution.

- Cooling System:

A 5.5W laser engraver normally require a cooling system,

such as an air mechanism, to disperse the heat created during the

engraving process and prevent laser module damage.

### 4.1.4 FINDINGS

We found out that the machine we built is a very accurate and a

tough competition to the competitor company like creality, wol3D

and man6y more company’s.

### 4.1.5 INFERENCE

We have used an open source software called “LaserGRBL”.

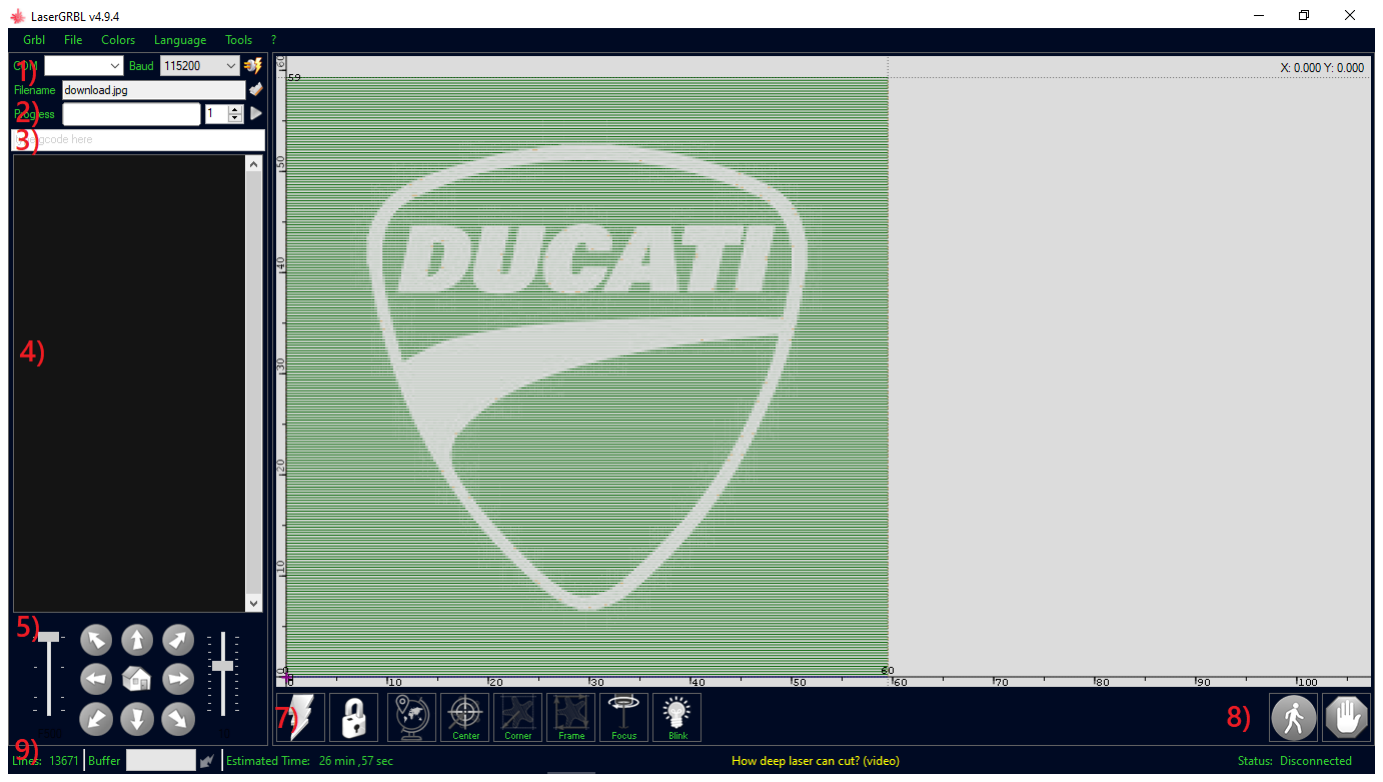
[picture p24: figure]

1. Connection control: (https://lasergrbl.com/usage/arduino-connection/) here you can select serial port and proper baud rate for

connection, according to grbl firmware configuration.

2. File control: (https://lasergrbl.com/usage/load-and-send/) this show loaded filename and engraving process progress. The

green “Play” button will start program execution.

3. Manual commands: you can type any G-Code line here and press “enter”.

Commands will be enquired to command queue.

### 4. Command log and command return codes: show enquired commands and their

execution status and errors.

5. Jogging control: (https://lasergrbl.com/usage/jogging/) allow manual positioning of the laser. The left vertical slider

control movement speed, right slider control step size.

### 6. Engraving preview: this area show final work preview. During engraving a

small blue cross will show current laser position at runtime.

7. | Grbl | reset/homing/unlock: | this | buttons | submit | soft-

reset, (https://github.com/gnea/grbl/wiki/Grbl-v1.1-Commands#ascii-realtime-command-descriptions) homing (https://github.com/gnea/grbl/wiki/Grbl-v1.1-Commands#h---run-homing-cycle) and unlock (https://github.com/gnea/grbl/wiki/Grbl-v1.1-Commands#x---kill-alarm-lock) command to grbl board. On the right of unlock

button you can add some user defined buttons. (https://lasergrbl.com/usage/custom-buttons/)

### 8. Feed hold and resume: this buttons can suspend and resume program execution

sending Feed Hold or Resume command (https://github.com/gnea/grbl/wiki/Grbl-v1.1-Commands#grbl--commands) to grbl board.

### 9. Line count and time projection: LaserGRBL could estimate program execution

time based on actual speed and job progress.

## CHAPTER 5

## 5.1 BUSSINESS ASPECTS

- VERSATILITY:

CNC laser engravers are very adaptable equipment that can

engrave and mark a broad range of materials, including wood, metal,

plastic, glass, leather, and others. This adaptability enables firms to

provide a varied range of products and services to meet the demands

of their customers.

- PRECISION AND QUALITY:

Laser engraving is extremely precise and creates high-

quality results. CNC laser engravers' precision and exquisite detail

make them excellent for a variety of applications, including bespoke

signs, personalised items, branding, and industrial marking.

- TIME AND COST EFFICIENCY:

CNC laser engravers can accomplish engraving operations

fast and efficiently, minimising manufacturing time when compared

to older techniques. CNC control systems minimise the need for

manual labour, lowering operational costs and eliminating mistakes.

- CUSTOMIZATION AND PERSONALIZATION:

Businesses may simply provide customised and personalised

items with CNC laser engraving. This expertise enables businesses

to target specialised markets and offer one-of-a-kind solutions such

as personalised gifts, promotional goods, and bespoke designs.

- SCALABILITY:

CNC laser engraving machines are capable of handling both

small and big production runs. This scalability enables organisations

to grow and cater to a variety of order sizes, from individual orders

to mass production.

- INTEGRATION WITH DIGITAL WORKFLOWS:

CNC laser engravers may function in conjunction with

digital design tools and workflows. This connection streamlines the

production process and allows for fast iterations and revisions by

facilitating the transmission of digital drawings to the machine.

- REDUCED WASTE AND ENVIRONMENTAL IMPACT:

Laser engraving is a non-contact procedure that reduces

material waste and has a low environmental impact. Laser

technology's accuracy assures fewer defects, decreasing the

requirement for rework or discarded materials. Furthermore,

because laser engraving does not utilise chemicals or inks, it is an

ecologically beneficial solution.

- DIVERSIFICATION AND MARKET OPPORTUNITIES:

Entrepreneurs may tap into a variety of sectors and industries

by introducing CNC laser engravers into their operations. These

machines are used in areas such as signs, jewellery, electronics,

automotive, aerospace, architecture, and many others, bringing up

new revenue sources.

- MAINTENANCE AND TRAINING:

It is critical to address the maintenance and training

requirements connected with CNC laser engravers. Regular

maintenance and calibration guarantee maximum machine

performance, while thorough operator training programmes

maximise productivity and reduce mistakes.

- COMPETITIVE ADVANTAGE:

Using CNC laser engraving technology may provide

businesses with a competitive advantage by delivering unique

goods, shorter turnaround times, and greater quality when compared

to rivals that use traditional engraving methods.

## 5.2 FINANCIAL CONSIDERATIONS

- INITIAL INVESTMENT:

The cost of purchasing the CNC laser engraving machine is

a crucial aspect. This covers the machine's purchase price as well as

any additional equipment or accessories required for operation.

Investigate several providers and models to get a sense of the price

range.

- OPERATING COSTS:

Determine the continuous costs of running the CNC laser

engraver. This covers fees for energy, maintenance and repair,

replacement components, and consumables including laser tubes,

lenses, and cooling fluids. These expenses must be considered in

order to estimate the long-term financial effects.

- LABOR COSTS:

Consider the labour costs associated with operating the

equipment. Calculate the associated wages or salaries if you intend

to engage operators. Furthermore, training fees may be spent to

guarantee that the operators are capable of running the equipment

safely and effectively.

- Costs of Facility:

Determine the space required for the CNC laser engraver

machine. Check that your facility has enough space and factor in any

additional costs involved with setting up or changing the workplace.

This might include ventilation systems, safety precautions, and

ergonomic concerns.

- Maintenance and Training:

It is critical to address the maintenance and training

requirements connected with CNC laser engravers. Regular

maintenance and calibration guarantee maximum machine

performance, while thorough operator training programmes

maximise productivity and reduce mistakes.

## 5.3 CONCLUSIONS

### 5.3.1 DESCRIBE STATE OF COMPLETION OF CAPSTONE

PROJECT.

Finally, the CNC laser engraver machine is a highly efficient and

adaptable instrument that provides significant advantages in a variety of

sectors. Throughout this research, we have investigated the machine's

capabilities, benefits, and prospective uses.

To begin with, the CNC laser engraving machine has excellent

precision and accuracy, allowing users to produce elaborate and precise

drawings on a variety of materials. Because it is computer-controlled, it

produces consistent outcomes while reducing human error and

enhancing productivity.

Another important feature is the machine's adaptability. It can

engrave on a variety of materials such as wood, acrylic, glass, metal, and

others. This adaptability enables it to serve a wide range of businesses,

including manufacturing, arts & crafts, signs, jewellery creation, and

personalised gift manufacture.

Furthermore, compared to traditional engraving processes, the CNC

laser engraver machine has significant benefits. It removes the need for

actual templates or stencils, saving time and money during setup. It also

allows for quick prototyping, which makes it perfect for small-scale

production and customisation.

Furthermore, the machine's software compatibility allows for simple

design generation and customization. Users can use specialist

programmes to develop their own designs or import designs from

popular graphic design applications. This user-friendly interface allows

both pros and amateurs to explore their creativity and generate high-

quality results.

The CNC laser engraving machine also has safety measures to

safeguard users and reduce the risks connected with laser use. These

safety precautions, which include emergency stop buttons, protective enclosures, and beam shields, help to provide a safe working

environment.

Overall, the CNC laser engraving machine is a sophisticated

instrument that enables users to realise their visions with precision,

efficiency, and variety. It has a wide range of possible uses, and it is

predicted | to | continue | revolutionising | sectors | by | improving
manufacturing | processes, | increasing | creativity, | and | boosting

innovation.

### 5.3.2 FUTURE WORK

By using this machine we can start our start up with help of using

platform like Instagram in which we could take orders and with the

help of the “CNC Laser engraver machine” we can make

personalised gifts as per requirements also we can use in the industry

for small work holds.

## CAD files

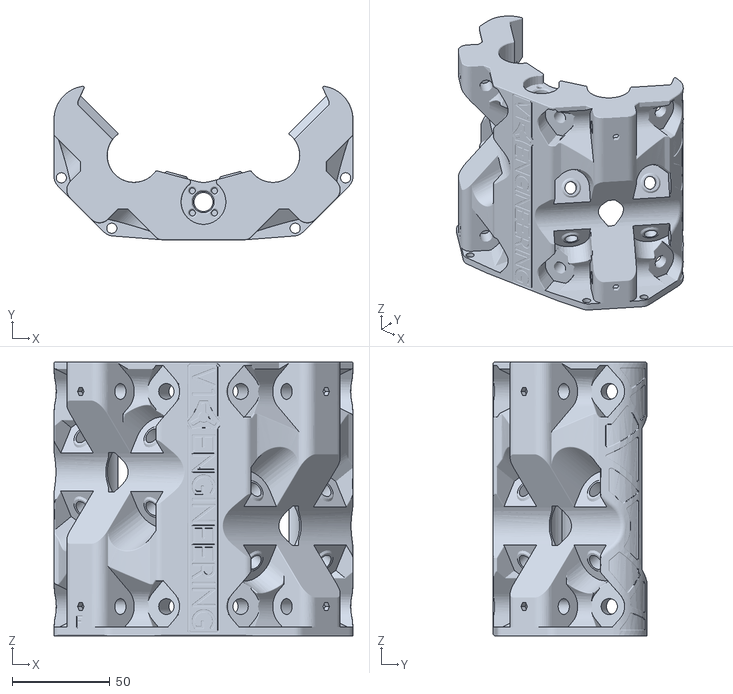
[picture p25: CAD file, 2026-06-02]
STL/Core F .STL
152.9 x 78.5 x 140.0

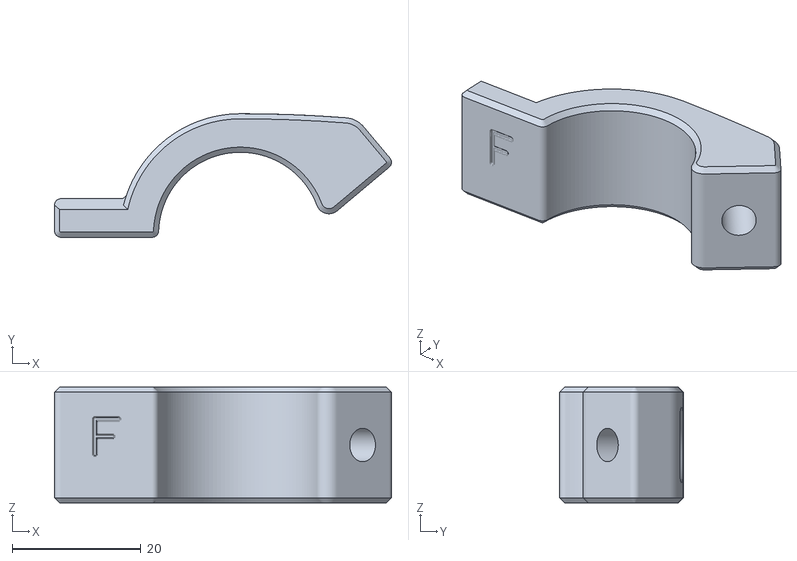
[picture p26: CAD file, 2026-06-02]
STL/Truck Clamp F .STL
52.4 x 19.2 x 18.0

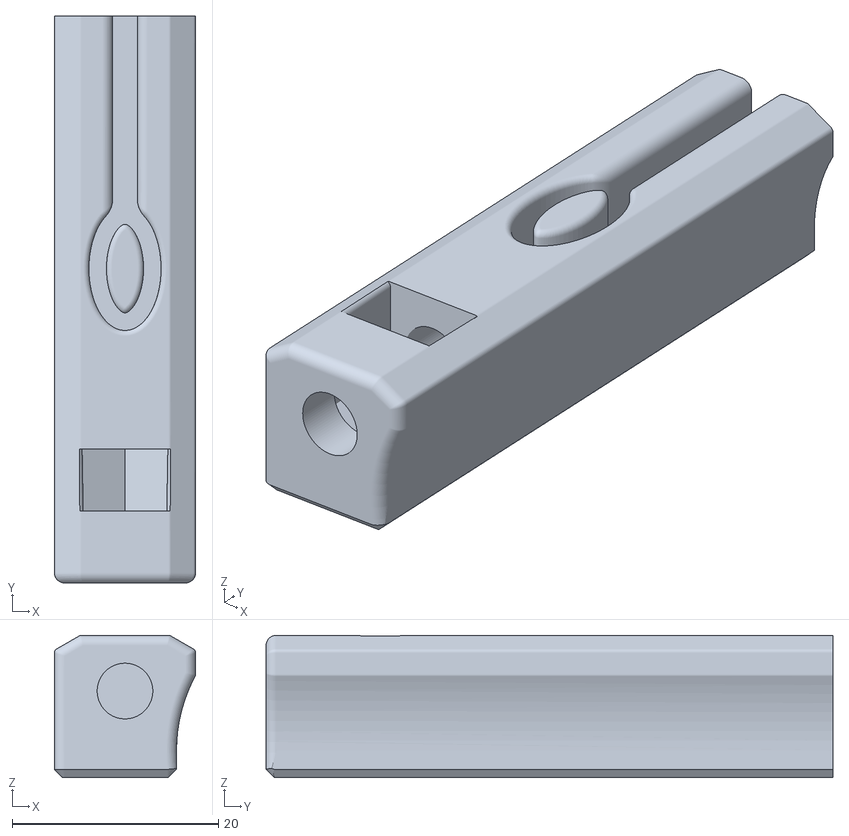
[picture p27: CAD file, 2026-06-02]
STL/Upper Belt F 2.STL
13.7 x 55.0 x 13.8

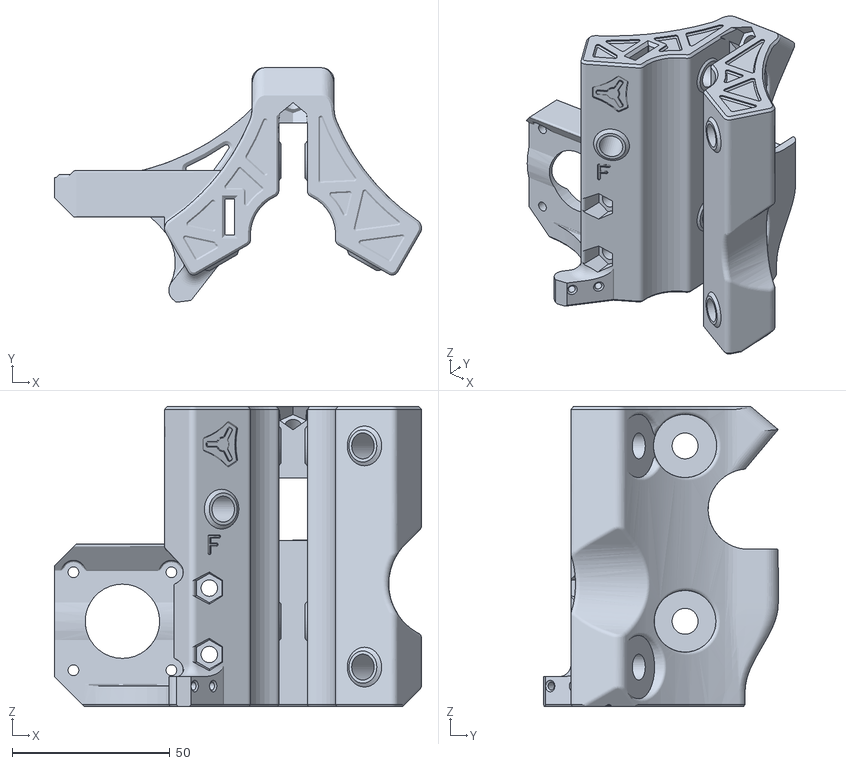
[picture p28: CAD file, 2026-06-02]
STL/Truck F .STL
116.2 x 74.2 x 95.0

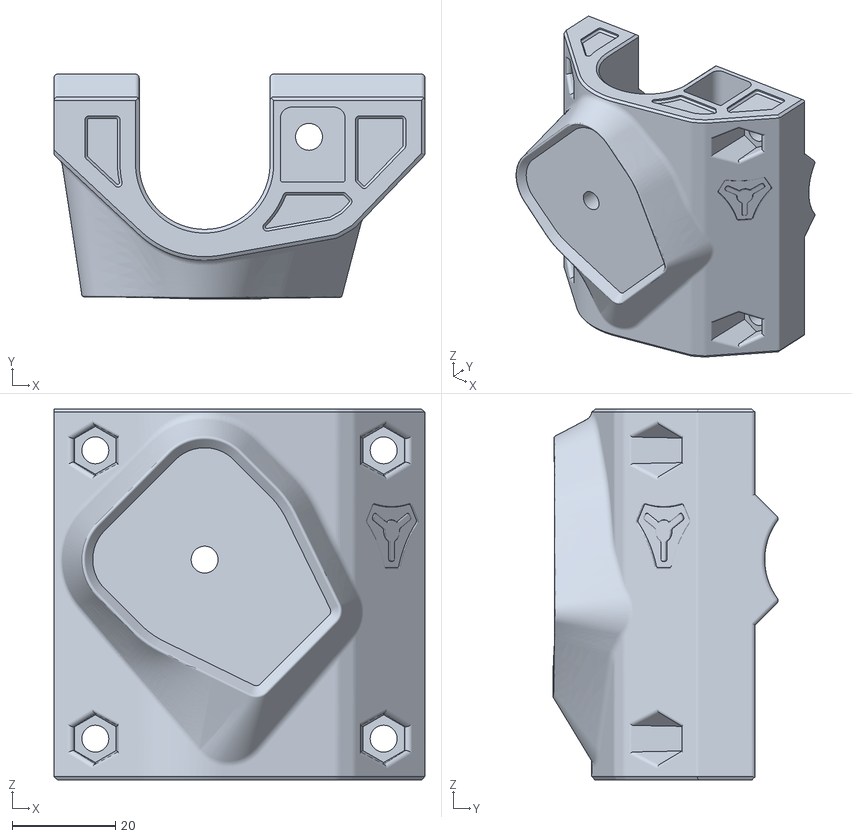
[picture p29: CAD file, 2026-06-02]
STL/Corner Bottom F 1.stl
71.8 x 43.6 x 71.8

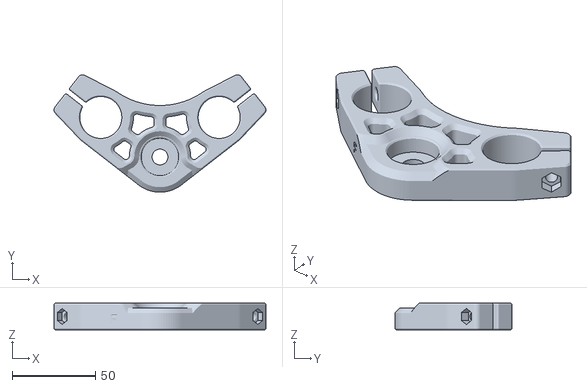
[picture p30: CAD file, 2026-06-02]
STL/Z Coupler F .STL
127.3 x 70.4 x 16.0

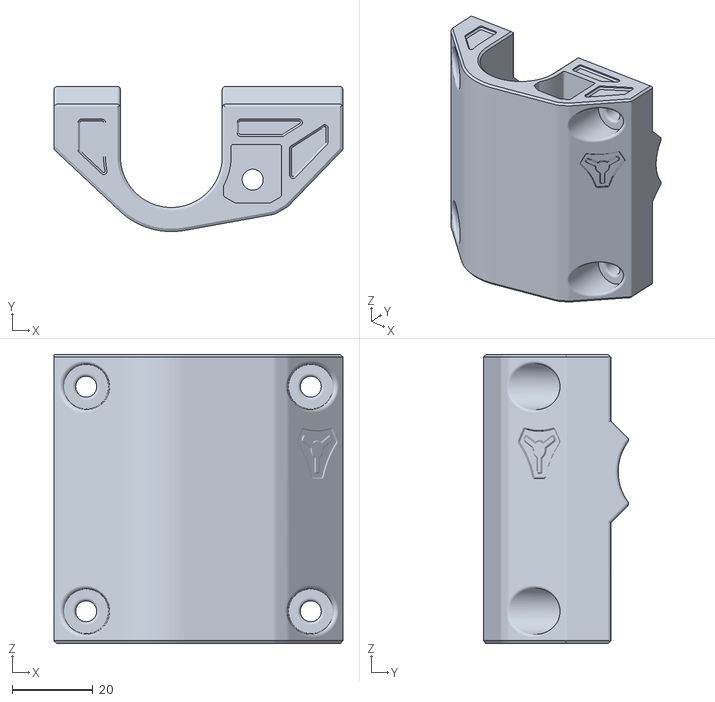
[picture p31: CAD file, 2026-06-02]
STL/Corner Top F1.stl
71.8 x 36.1 x 71.8

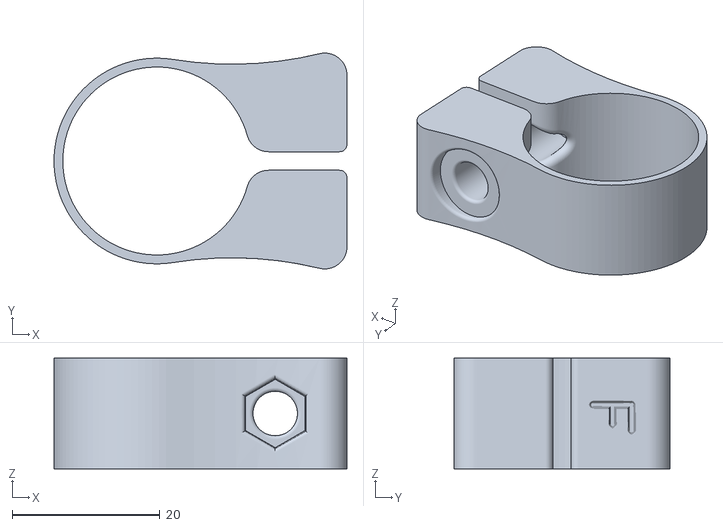
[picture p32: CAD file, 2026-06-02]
STL/Stop Block 25.STL
39.6 x 29.2 x 15.0

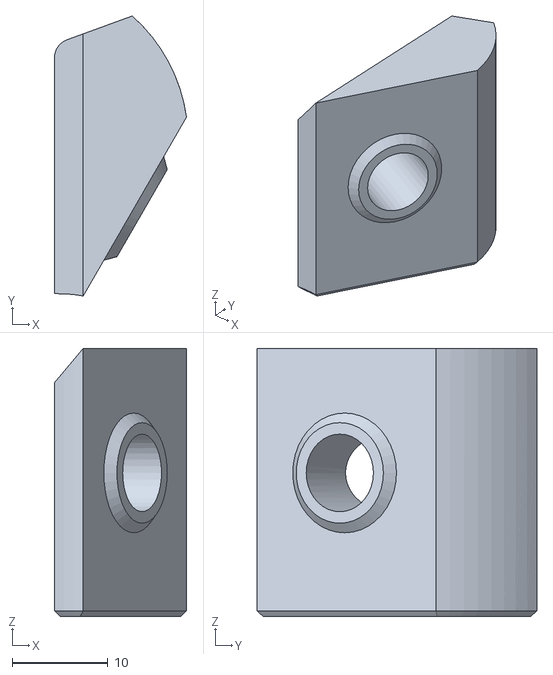
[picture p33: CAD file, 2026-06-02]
STL/Core Z Clamp 1 F .STL
13.8 x 29.2 x 28.0

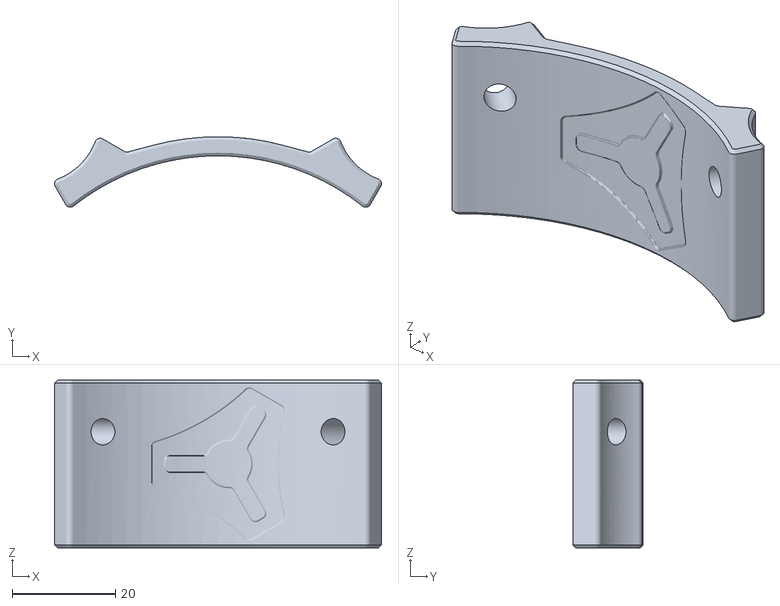
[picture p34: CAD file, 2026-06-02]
STL/Lower Tool Plate F.STL
63.3 x 13.7 x 32.5

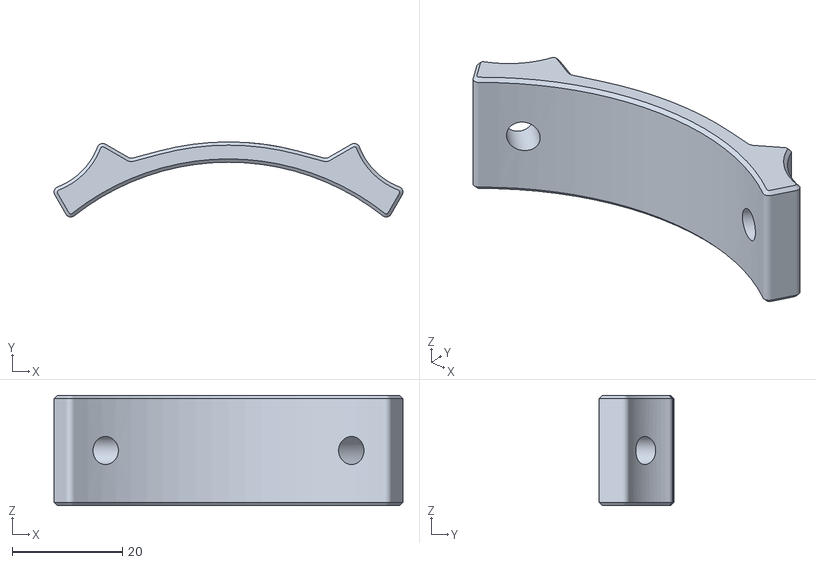
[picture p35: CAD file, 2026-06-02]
STL/Upper Tool Plate F .STL
63.3 x 13.7 x 20.0

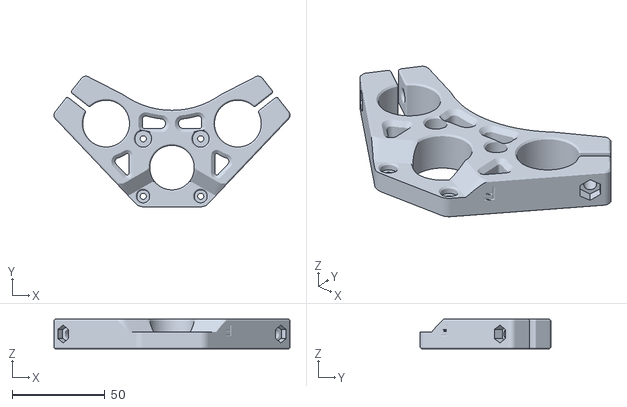
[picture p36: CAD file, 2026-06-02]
STL/Z Motor F .STL
127.3 x 70.5 x 16.0

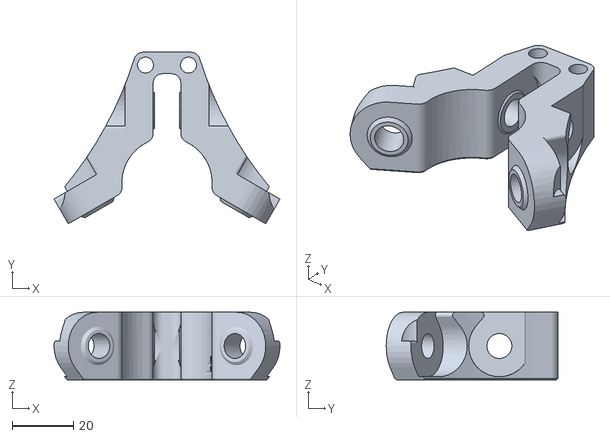
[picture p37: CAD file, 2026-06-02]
STL/Core Clamp F .STL
73.6 x 55.9 x 22.0

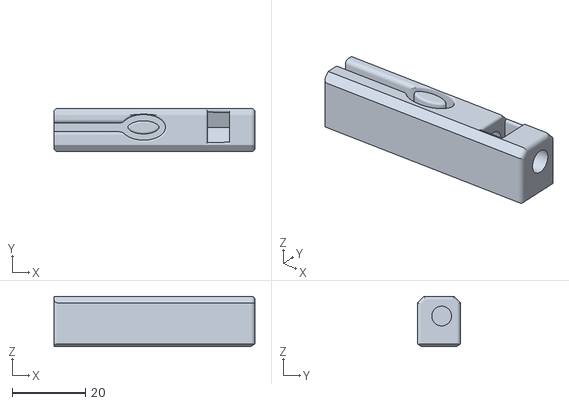
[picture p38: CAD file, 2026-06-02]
STL/Lower Belt F1.stl
55.0 x 11.8 x 13.8

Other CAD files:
STL/Corner Bottom F 2.STL
STL/Corner Top F 2.STL
STL/Corner Leg Lock F.STL
STL/Upper Belt F 1.stl
STL/Core Clamp Y F .STL
STL/Core Z Clamp 2 F .STL
STL/Feet F.STL
STL/Lower Belt F 2.STL
STL/Nut Trap .STL
STL/Truck F.stl
STL/Wire Darryl.STL

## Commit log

2026-06-02 Initial commit: CNC Laser Engraver STL models and project documentation
    [Core Clamp F .STL, Core Clamp Y F .STL, Core F .STL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]
2026-06-02 Add interactive mechatronics assembly page and G-code simulator
